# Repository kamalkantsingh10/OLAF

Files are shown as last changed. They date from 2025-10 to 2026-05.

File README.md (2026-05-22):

# 🤖 OLAF

**An open-source AI companion robot. Built in public.**

<p align="center">
  <a href="https://youtube.com/shorts/9D4Txb85EnM">
    OLAF cycling through its expressions — click to watch<br>
    <b>▶ Watch OLAF cycle through its expressions</b>
  </a>
</p>

---

## The Journey: 20 Weeks and Counting

<table>
  <tr>
    <td width="33%" align="center">
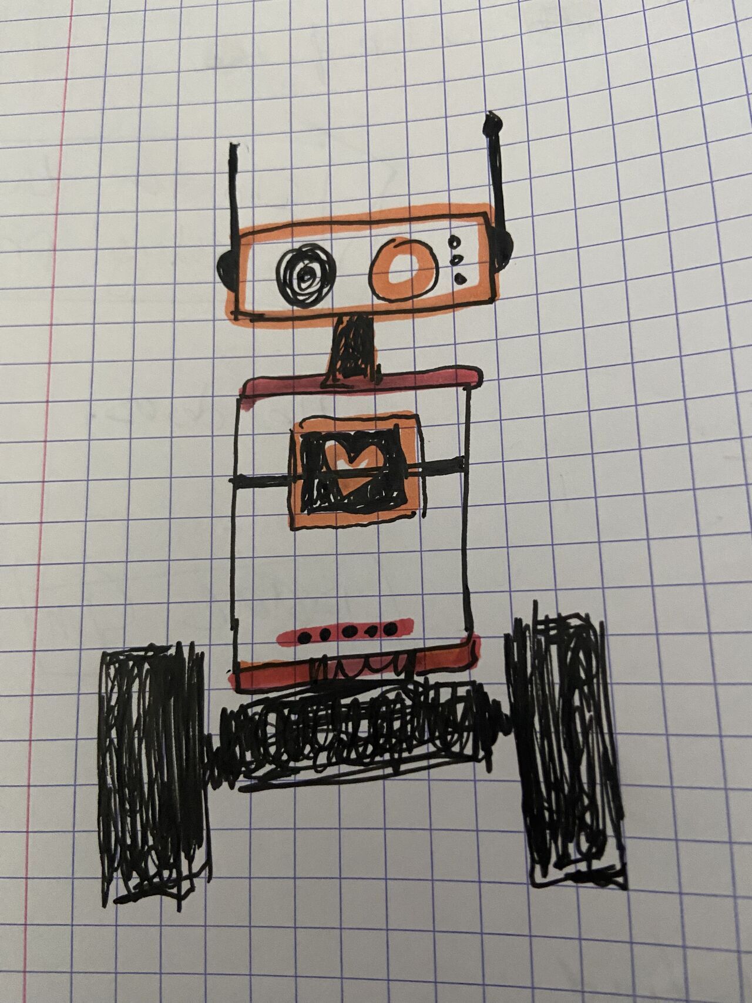
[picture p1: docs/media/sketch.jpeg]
Week 0: Initial Sketch
      <br>
      <b>Week 0</b><br>Initial concept sketch
    </td>
    <td width="33%" align="center">
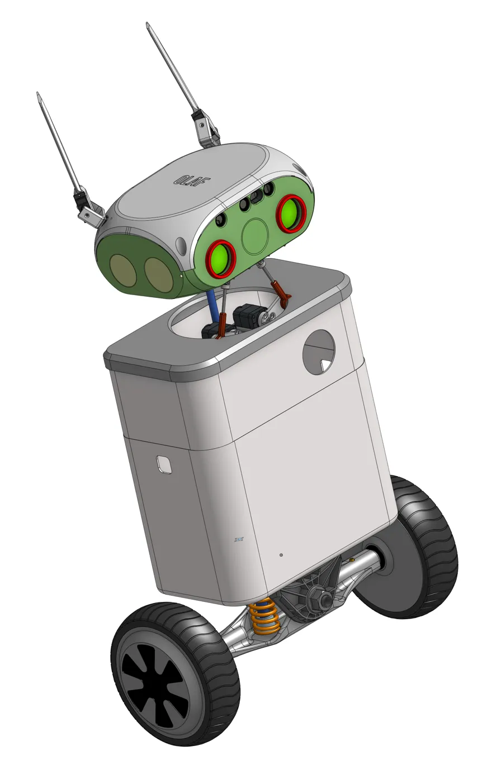
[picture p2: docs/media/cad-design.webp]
Week 8: CAD Design
      <br>
      <b>Week 8</b><br>3D CAD design complete
    </td>
    <td width="33%" align="center">
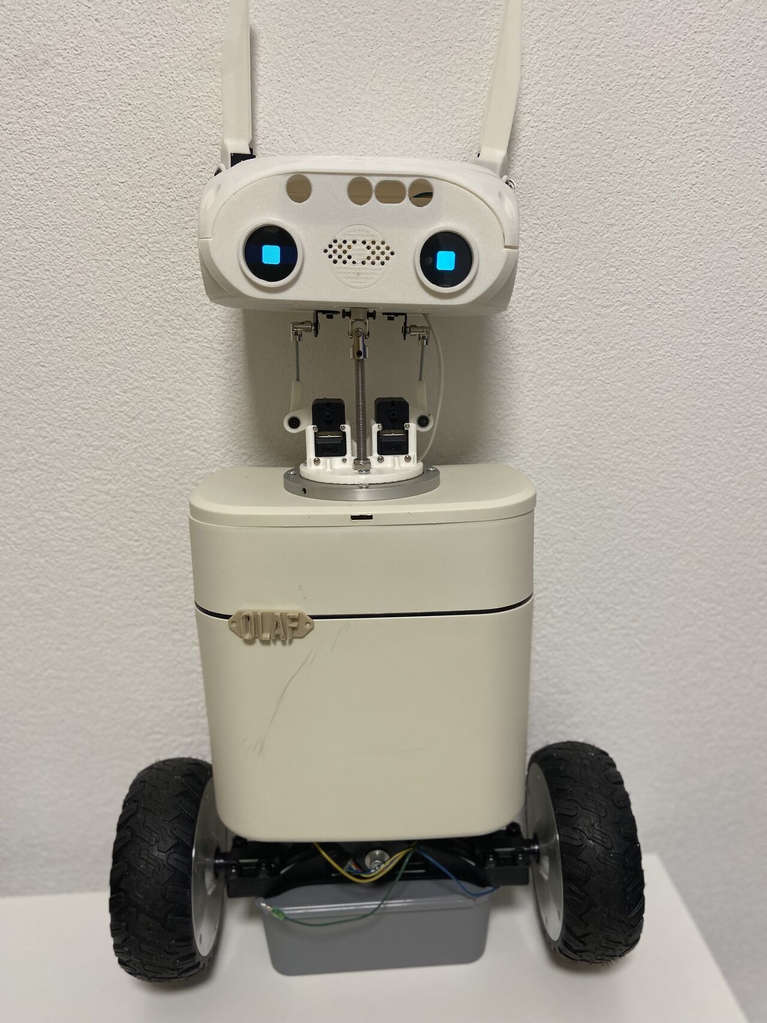
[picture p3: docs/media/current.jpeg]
Week 20: First Module Working
      <br>
      <b>Week 20</b><br>Head alive — eyes, ears & neck expressing
    </td>
  </tr>
</table>

**An active build-in-public project.** Built while relocating cities and starting a new job — learning CAD, ROS2, embedded systems, and AI integration as I go, with AI coding assistants accelerating development. The journey continues!

---

## What is OLAF?

OLAF is a **personality-first robotics framework** that brings AI agents into physical form. Think R2D2's charm meeting modern AI capabilities — a 2-3 foot tall companion that communicates through expressive OLED eyes, articulated ears (Chappie-inspired), an animated heart display, R2D2-style beeps, and LED status indicators.

**This is not another voice assistant in a box.**

When you BUILD your AI companion, something fundamental changes. It becomes a partner, not a servant. JARVIS challenges Tony Stark's ideas. R2D2 takes initiative. The difference? Tony BUILT JARVIS. Luke CHOSE R2D2 and they grew together. **Building creates relationship, and relationship enables true collaboration.**

---

## The Problem We're Solving

AI assistants (Alexa, Siri, ChatGPT, Claude) have impressive reasoning but remain fundamentally **disembodied** — trapped in screens and speakers. Meanwhile, building physical AI with personality forces impossible choices:

| Option | What You Get | What You Lose |
|---|---|---|
| **Commercial robots** (Boston Dynamics, Vector) | Polish, capability | $1000s+, closed-source, no customization |
| **Educational platforms** (Poppy, Niryo) | Modularity, learning | AI integration, personality, high cost |
| **ROS2 robots** (Linorobot2, Andino) | Excellent navigation | Zero personality, assistant features |
| **Hobbyist kits** (Otto DIY) | Affordable, charming | Limited capabilities, no AI |
| **Closed AI robots** (HIWONDER) | AI + robotics bridge | Generic design, closed ecosystem |

**The Core Gap:** No open-source framework integrates modular architecture + AI conversation + personality expression + practical assistance + maker-accessible approach + community ecosystem.

**The Opportunity:** All the pieces are finally here — 3D printers, powerful LLMs, modern SBCs (Raspberry Pi 5), AI coding assistants, local AI accelerators (Hailo). **This is the democratization moment.** The future of embodied AI belongs to builders, not just consumers.

---

## Architecture: Three Layers, Five Modules

> **Repo scope (Phase 2, 2026-05-15).** This repository is the **OLAF body / expression engine** — the Orchestration + Module layers below. The Intelligence Layer (STT, reasoning, personality, mood/emotion decisions) is a **separate sibling project, `olaf_companion`**, which publishes 4 canonical ROS 2 topics (`mood`, `activity`, `speech_emotion`, `vocalization`). This repo subscribes to those and renders them on the body. The "personality-first" vision is unchanged at the *system* level; it's just split across two repos. See `docs/sprint-change-proposal-2026-05-15.md`.

```
┌─────────────────────────────────────────────────────────────────┐
│   INTELLIGENCE LAYER (Hybrid AI) — sibling repo olaf_companion  │
│                                                                 │
│  Local AI (Hailo-accelerated):                                 │
│    • Whisper STT (<200ms latency)                              │
│    • Real-time vision processing                               │
│                                                                 │
│  Cloud AI Agents (Claude/GPT-4):                               │
│    • Natural language understanding                            │
│    • Complex reasoning & decision-making                       │
│    • Tool use, function calling, multi-step planning           │
│                                                                 │
└──────────────────────┬──────────────────────────────────────────┘
                       │ 4 canonical ROS 2 topics
                       │ (mood · activity · speech_emotion · vocalization)
┌──────────────────────▼──────────────────────────────────────────┐
│              ORCHESTRATION LAYER  ◀── THIS REPO                 │
│      Raspberry Pi 5 16GB + Fusion HAT+ + Hailo AI Kit          │
│               Ubuntu 24.04 • ROS2 Jazzy                         │
│                                                                 │
│  • Expression Engine (subscribes to olaf_companion's 4 topics) │
│  • Composes activity → mood → speech_emotion → vocalization    │
│  • Renders pose/LED/eye/heart from expression_map.yaml         │
│  • Direct Hardware Control (servos, LEDs, kickstand via HAT)   │
│  • I2C Master for ESP32 modules                                │
│                                                                 │
└──┬───────┬───────┬─────────────────┬───────────────────────────┘
   │       │       │                 │
   │I2C    │USB×2  │HAT WS2812       │HAT PWM
   │       │       │                 │
┌──▼───┐ ┌─▼─────────────┐ ┌────────▼───┐ ┌──▼──────┐
│ HEAD │ │ WAVESHARE USB │ │ INDICATOR  │ │KICKSTAND│
│ESP32 │ │ Neck + Ears   │ │ 24 LEDs    │ │ Servos  │
│(0x10)│ │ Servo Adapters│ │ (3 strips) │ │(at base)│
└──────┘ └───────────────┘ └────────────┘ └──▲──────┘
┌──▼───┐                                      │
│ BASE │                                      │
│ESP32 │                                      │
│(0x11)│                                      │
└──────┘
```

### The Five Modules (MECE Principle)

Each module owns its domain exclusively — no cross-dependencies. **Hybrid control:** ESP32s for real-time tasks, Pi direct control for latency-tolerant hardware.

**1. HEAD Module (ESP32, I2C 0x10)**
- **Hardware:** 2× GC9A01 round OLED eyes (240×240, SPI 30-60 FPS), ESP32-S3 for real-time eye animation
- **Personality:** Animated eye expressions, smooth emotional transitions, blink patterns
- **Why ESP32:** 60 FPS animation requires dedicated real-time control

**2. BASE Module (ESP32, I2C 0x11)**
- **Hardware:** Two-wheel inverted pendulum, hoverboard BLDC motors, ODrive v3.6 (UART), BNO085 9-axis AHRS (200Hz on-chip sensor fusion)
- **Control:** 200Hz PID balancing loop (hard real-time, Linux can't guarantee this)
- **Why ESP32:** Self-balancing requires hard real-time guarantees

**3. NECK Module (Pi-controlled, USB Serial)**
- **Hardware:** 3× Feetech STS3215 servos (pan/tilt/roll), Waveshare Bus Servo Adapter
- **Personality:** Head orientation, expressive gestures (tilts, nods, shakes) with organic easing
- **Why Pi Direct:** USB serial via Waveshare adapter — no soldering, plug-and-play

**4. EARS Module (Pi-controlled, USB Serial)**
- **Hardware:** 4× Feetech SCS0009 servos (2-DOF × 2 ears), Waveshare Bus Servo Adapter
- **Personality:** Chappie-inspired ears — perked = alert, drooping = sad, swiveling = curious
- **Why Pi Direct:** USB serial via Waveshare adapter — no soldering, plug-and-play

**5. INDICATOR Module (Pi-controlled, Fusion HAT WS2812)**
- **Hardware:** 3× 8-LED WS2812 strips (24 LEDs, daisy-chained)
- **Functions:** interaction state (listening/working/speaking) · module health · PID visualization
- **Why Pi Direct:** Single data line via Fusion HAT WS2812 port

**Additional Pi-controlled hardware:** 4" heart display (animated beating heart) · kickstand (2× landing-gear servos via HAT PWM) · I2S speaker via HAT.

### Why This Architecture?

- **Hybrid control topology** — ESP32s for the two real-time-critical jobs (60 FPS eyes, 200Hz balancing); Pi direct (via Fusion HAT) for everything else. Minimal soldering, fewer firmware projects, maximum reliability.
- **Modular MECE** — each module completable in 1-2 weekend sprints, independently testable, contribution-friendly.
- **Hybrid intelligence** — local AI (Hailo) for fast/private sensing; cloud agents for sophisticated reasoning.
- **ROS2 foundation** — industry-standard pub/sub on ROS2 Jazzy / Ubuntu 24.04, with a rich ecosystem (SLAM, navigation, sensor fusion).

---

## How Expression Works

The expression engine is a ROS2 node that turns "what the companion is feeling/doing" into coordinated motion + light across every channel — in real time, from a single data-driven map.

```
companion topics ─▶ activity base ─▶ + mood bias ─▶ + speech_emotion ─▶ + vocalization
(mood/activity/      (posture)        (LED tint /     (12 authored        (transient
 speech/voc)                           idle drift)     emotions)            gestures)
                                                              │
                                                              ▼
                                          eyes (OLED) · ears · neck · WS2812 LEDs
```

- **Single source of truth:** `ros2/src/expression_engine/config/expression_map.yaml` (+ `neck_motion.yaml`, `ears_motion.yaml`). See the [config index](ros2/src/expression_engine/config/README.md).
- **Additive composition:** later layers ride on top of earlier ones, so a vocalization gesture never wipes the underlying emotional pose.
- **Hand-authored, hardware-tuned:** every emotion is authored, then frozen after a pass on the real avatar.

---

## Current Status

**🔄 Active build-in-public (Phase 2 — Expression Engine).** This is a work-in-progress; here's what's real today.

**✅ Working on real hardware:**
- **Head / eyes** — 2× OLED eyes animated by ESP32 firmware; a full set of distinct expressions (the video above)
- **Ears** — 4× SCS0009 servos: perk / droop / swivel, hardware-calibrated
- **Neck** — 3× STS3215 servos: pan / tilt / roll with organic easing
- **Expression engine (ROS2 Jazzy)** — subscribes to the companion's 4 canonical topics and drives eyes + ears + neck + LEDs in sync
- **Idle behaviour** — head drifts to sleep when idle, stirs awake on activity
- **Status LEDs** — WS2812 strips reflect listening / working / speaking

**🔨 In progress / next:**
- Expression authoring finalization (Epic 7 — in review: speech emotions, vocalizations, activity postures, mood→LED tint)
- Heart display animation (Epic 8)
- Self-balancing base — PID tuning (experimental)
- SLAM navigation (deferred)

**🔗 Companion brain:** the AI/intelligence layer lives in the sibling repo **`olaf_companion`**, which publishes the 4 topics this body renders.

**Realistic timeline:** a complex build done in spare time while working full-time. Progress is incremental, iterative, and documented as it happens.

---

## 📹 Demo Videos

### May 2026
- **OLAF expression cycling** — *2026-05-20* — the expression engine cycling through OLAF's authored emotions on real hardware (OLED eyes, articulated ears, 3-DOF neck). [▶ Watch on YouTube](https://youtube.com/shorts/9D4Txb85EnM)

---

## Repository Organization

**Module-first structure.** Everything for a module lives in one place.

```
modules/
├── head/             # OLED eyes (ESP32, I2C 0x10)
├── base/             # Self-balancing (ESP32, I2C 0x11)
├── neck/             # 3-DOF servos (Pi USB serial)
├── ears/             # Articulated ears (Pi USB serial)
├── indicator/        # WS2812 LED strips (Pi Fusion HAT)
└── shared/           # Shared ESP32 libraries
```

**ESP32 modules** (head, base): `firmware/` (PlatformIO) · `hardware/` (3D models + BOM) · `tests/` · `wiring.md`.
**Pi-controlled modules** (neck, ears, indicator): `hardware/` · `tests/` · `assembly.md`.

**ROS2 lives separately:**
```
ros2/src/
├── olaf_drivers/       # Driver logic (head_ears, neck, base, torso)
├── expression_engine/  # Phase 2: renders olaf_companion's 4 canonical topics
└── olaf_ai/            # (deferred) STT/agents now in olaf_companion
```

**Full details:** see [repository-structure.md](docs/architecture/repository-structure.md).

---

## License & Credits

**License:** Open Source (TBD: MIT or Apache 2.0)

**Builder:** [Kamal Singh](https://www.linkedin.com/in/kamal-singh)
- 15 years in tech (5 at Amazon) · 1 year intentional AI deep-dive · MBA + full-stack (hardware + software + AI)

**Inspiration:** R2D2 (non-verbal personality) · JARVIS (AI partner, not servant) · Chappie (expressive ears) · Wall-E (friendly retro-futurism).

**Built with:** AI coding assistants (Claude, GPT-4) · Raspberry Pi 5 16GB / Ubuntu 24.04 · Sunfounder Fusion HAT+ · Hailo AI Kit (26 TOPS) · ROS2 Jazzy · ESP32-S3 · Waveshare Bus Servo Adapters · OnShape · PlatformIO.

---

## Tags

`#BuildInPublic` `#Robotics` `#ROS2` `#PhysicalAI` `#OpenSource` `#MakerMovement` `#AI` `#LearnInPublic` `#EmbodiedAI` `#ModularRobotics`

---

<p align="center">
  <i>"Feel alive first, be useful second."</i>
</p>

<p align="center">
  <b>Star ⭐ this repo if you believe the future of AI should be open and collaborative!</b>
</p>

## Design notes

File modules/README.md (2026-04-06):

# OLAF Modules

Complete subsystems for OLAF's four smart peripheral modules.

## Module Overview

Each module is a **self-contained unit** with its own:
- **Firmware** (ESP32 code)
- **Hardware** (PCB designs, 3D models)
- **Tests** (Module-specific integration tests)
- **Diagnostics** (Debug and calibration tools)
- **Scripts** (Build, flash, test automation)
- **Documentation** (Wiring, assembly guides)

## Modules

| Module | I2C Address | Key Components | Status |
|---|---|---|---|
| **[head-ears](head-ears/)** | 0x08 | 2× OLED eyes, 2× articulated ears, floor projector control | In Development |
| **[neck](neck/)** | 0x09 | 3-DOF servo array, 2× presence sensors | Designed |
| **[torso](torso/)** | 0x0A | Heart display, thermal printer, battery, Pi housing | In Development |
| **[base](base/)** | 0x0B | ODrive motors, BNO085 AHRS IMU, self-balancing | Designed |

## Quick Start

### Build a Module

```bash
cd modules/head-ears/firmware
pio run
```

### Flash a Module

```bash
cd modules/head-ears/firmware
pio run --target upload
```

### Test a Module

```bash
cd modules/head-ears
pytest tests/
```

### Run Diagnostics

```bash
cd modules/head-ears
python3 diagnostics/projector_diagnostic.py
```

## Development Workflow

1. **Navigate to module:** `cd modules/head-ears`
2. **Everything is here:**
   - Firmware code: `firmware/src/`
   - Hardware designs: `hardware/pcb/`, `hardware/mechanical/`
   - Tests: `tests/`
   - Tools: `diagnostics/`, `scripts/`
   - Docs: `wiring.md`, `assembly.md`, `README.md`

3. **Build → Flash → Test:**
   ```bash
   cd firmware && pio run --target upload
   cd ../tests && pytest
   cd ../diagnostics && python3 module_health.py
   ```

## Shared Resources

**Location:** `modules/shared/`

- **Firmware:** I2C protocol, OTA handlers, utilities
- **Hardware:** KiCad libraries, common 3D parts

All modules include shared libraries:
```ini
# In platformio.ini
lib_extra_dirs = ../../shared/firmware
```

## Module Architecture

Each module follows the **Smart Peripheral Pattern**:

1. **I2C Slave Interface:** Receives commands from Raspberry Pi
2. **Hardware Drivers:** Direct control of sensors/actuators
3. **Animation Engine:** Local execution of motion/display patterns
4. **Real-Time Control:** Critical timing loops (e.g., 200Hz PID on base)

**Example:** Head+Ears receives `PROJECTOR_ON` via I2C, then autonomously controls power (optocoupler) and focus (servo) without further Pi intervention.

## System Integration

Modules communicate via:
- **I2C bus:** Commands from Pi, sensor data to Pi
- **ROS2 topics:** High-level semantic interface (via driver nodes in `ros2/src/olaf_drivers/`)
- **Shared ground:** All modules share common electrical ground

See `hardware/wiring/` for inter-module wiring diagrams.

## Adding a New Module

1. Create directory: `modules/new-module/`
2. Copy structure from existing module (e.g., `head-ears/`)
3. Update I2C address in `firmware/platformio.ini`
4. Create ROS2 driver in `ros2/src/olaf_drivers/new_module_driver/`
5. Document in `new-module/README.md`

## Resources

- **System Architecture:** See `docs/architecture.md`
- **I2C Protocol:** See `modules/shared/firmware/i2c-protocol/`
- **Wiring Guide:** See `docs/guides/wiring-guide.md` and `hardware/wiring/`
- **Module Documentation:** See each module's `README.md`

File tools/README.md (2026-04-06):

# Tools

Development and debugging utilities for OLAF.

## Structure

```
tools/
├── diagnostics/    # System diagnostics
├── calibration/    # Sensor/servo calibration
├── simulators/     # Hardware-in-the-loop simulators
└── utils/          # General utilities
```

## Diagnostics

**Location:** `tools/diagnostics/`

System health checks and debugging:

### i2c_scanner.py

Scan I2C bus for connected modules:

```bash
python3 tools/diagnostics/i2c_scanner.py
```

Output:
```
Found devices at: 0x08 (Head+Ears), 0x09 (Neck), 0x0A (Torso), 0x0B (Base)
```

### module_health_check.py

Check health status of all modules:

```bash
python3 tools/diagnostics/module_health_check.py
```

Reports:
- Firmware version
- Uptime
- Error counts
- Temperature
- I2C communication status

### odrive_diagnostic.py

ODrive motor controller diagnostics:

```bash
python3 tools/diagnostics/odrive_diagnostic.py
```

Checks:
- Motor calibration status
- Encoder alignment
- Current limits
- Bus voltage

## Calibration

**Location:** `tools/calibration/`

Calibrate sensors and actuators:

### servo_calibrator.py

Calibrate servo ranges and positions:

```bash
# Interactive calibration
python3 tools/calibration/servo_calibrator.py --module head-ears

# Auto-calibrate with defaults
python3 tools/calibration/servo_calibrator.py --module neck --auto
```

Saves calibration to `config/firmware/{module}_servo_cal.json`

### imu_calibrator.py

Calibrate BNO085 IMU (9-axis AHRS with on-chip sensor fusion):

```bash
python3 tools/calibration/imu_calibrator.py
```

BNO085 calibration procedure:
1. Place robot stationary on flat surface for ~30 seconds (accel/gyro auto-calibrate)
2. Slowly rotate robot in figure-8 pattern for magnetometer calibration
3. Script saves calibration data to ESP32 flash via `sh2_saveDcdNow()`
4. Tare sets current upright orientation as pitch=0° reference

### camera_calibrator.py

Calibrate RGBD camera intrinsics:

```bash
python3 tools/calibration/camera_calibrator.py --checkerboard 9x6 --size 0.025
```

Uses checkerboard pattern for calibration.

## Simulators

**Location:** `tools/simulators/`

Test without physical hardware:

### i2c_module_simulator.py

Simulate ESP32 modules for development:

```bash
# Simulate all modules
python3 tools/simulators/i2c_module_simulator.py

# Simulate specific module
python3 tools/simulators/i2c_module_simulator.py --module head-ears
```

Emulates I2C slave behavior, useful for:
- ROS2 driver development without hardware
- Integration testing
- CI/CD pipelines

## Utilities

**Location:** `tools/utils/`

General-purpose utilities:

### log_analyzer.py

Analyze ROS2 and firmware logs:

```bash
python3 tools/utils/log_analyzer.py logs/olaf_2024-01-15.log
```

Extracts:
- Error patterns
- Performance metrics
- Event timelines

## Usage Examples

### Initial Setup

```bash
# 1. Scan for modules
python3 tools/diagnostics/i2c_scanner.py

# 2. Check module health
python3 tools/diagnostics/module_health_check.py

# 3. Calibrate servos
python3 tools/calibration/servo_calibrator.py --module head-ears
python3 tools/calibration/servo_calibrator.py --module neck

# 4. Calibrate IMU (for base module)
python3 tools/calibration/imu_calibrator.py
```

### Development Without Hardware

```bash
# Start I2C simulator
python3 tools/simulators/i2c_module_simulator.py &

# Launch ROS2 drivers (will connect to simulator)
ros2 launch olaf_bringup drivers.launch.py
```

### Troubleshooting

```bash
# Module not responding?
python3 tools/diagnostics/i2c_scanner.py
python3 tools/diagnostics/module_health_check.py

# Motors behaving oddly?
python3 tools/diagnostics/odrive_diagnostic.py

# Check logs
python3 tools/utils/log_analyzer.py logs/latest.log
```

## Requirements

Install Python dependencies:

```bash
pip install smbus2 pyserial numpy opencv-python
```

Or via Poetry (from project root):

```bash
poetry install
```

## Adding New Tools

When creating new tools:

1. Place in appropriate category folder
2. Make executable: `chmod +x tool.py`
3. Add shebang: `#!/usr/bin/env python3`
4. Include `--help` argument
5. Document usage in this README

Example template:

```python
#!/usr/bin/env python3
"""
Brief description of tool.
"""
import argparse

def main():
    parser = argparse.ArgumentParser(description="Tool description")
    parser.add_argument("--option", help="Option description")
    args = parser.parse_args()

    # Tool logic here

if __name__ == "__main__":
    main()
```

## Resources

- [I2C Protocol Specification](../docs/api/i2c-protocol.md)
- [Calibration Guide](../docs/guides/calibration.md)

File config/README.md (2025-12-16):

# Configuration

Runtime configuration files for OLAF's firmware, ROS2 nodes, and I2C bus.

## Structure

```
config/
├── i2c/        # I2C bus configuration
├── ros2/       # ROS2 node parameters
└── firmware/   # Firmware configuration (WiFi, OTA URLs)
```

## I2C Configuration

**Location:** `config/i2c/`

### bus_config.yaml

I2C bus settings:

```yaml
bus_speed: 400000  # 400 kHz (standard) or 1000000 (fast mode)
bus_number: 1      # /dev/i2c-1 (Raspberry Pi default)
timeout_ms: 100    # Read/write timeout

modules:
  head_ears:
    address: 0x08
    enabled: true
  neck:
    address: 0x09
    enabled: true
  torso:
    address: 0x0A
    enabled: true
  base:
    address: 0x0B
    enabled: true
```

## ROS2 Configuration

**Location:** `config/ros2/`

### drivers.yaml

Hardware driver node parameters:

```yaml
head_ears_driver:
  ros__parameters:
    i2c_address: 0x08
    update_rate: 30.0  # Hz
    projector:
      default_focus: 128
      power_timeout: 5.0  # seconds
    eyes:
      brightness: 200
      fps: 60

neck_driver:
  ros__parameters:
    i2c_address: 0x09
    servo_count: 3
    movement_smoothing: 0.8

# ... more driver configs
```

Load with:
```bash
ros2 launch olaf_bringup drivers.launch.py config:=config/ros2/drivers.yaml
```

### personality.yaml

Personality engine parameters:

```yaml
emotion_engine:
  ros__parameters:
    default_emotion: neutral
    transition_time: 1.0  # seconds
    energy_level: 0.7

expression_sync:
  ros__parameters:
    max_latency_ms: 500
    sync_eyes_ears: true
```

### navigation.yaml

Nav2 stack parameters (extensive, see Nav2 docs):

```yaml
controller_server:
  ros__parameters:
    use_sim_time: false
    controller_frequency: 20.0
    # ... more Nav2 params
```

## Firmware Configuration

**Location:** `config/firmware/`

### wifi_config.json

WiFi credentials for OTA updates (gitignored, template provided):

```json
{
  "ssid": "YourNetworkName",
  "password": "YourPassword",
  "hostname": "olaf-robot"
}
```

**Security Note:** Never commit this file! Use `wifi_config.json.template` as reference.

### ota_config.yaml

OTA update server configuration:

```yaml
ota_server:
  host: "192.168.1.100"  # Raspberry Pi IP
  port: 8080
  check_interval: 3600  # seconds (1 hour)
  auto_update: false

modules:
  head_ears:
    firmware_url: "http://192.168.1.100:8080/firmware/head-ears/latest.bin"
    version_url: "http://192.168.1.100:8080/firmware/head-ears/version.txt"
  # ... more modules
```

### module_calibration/

Per-module calibration data:

- `head_ears_servo_cal.json` - Ear servo calibration
- `neck_servo_cal.json` - Neck servo calibration
- `base_imu_cal.json` - IMU calibration offsets
- `camera_intrinsics.yaml` - Camera calibration

Generated by calibration tools (`tools/calibration/`).

## Environment-Specific Configs

Use different configs for dev/production:

```bash
# Development (with simulator)
ros2 launch olaf_bringup olaf.launch.py config:=config/ros2/drivers_sim.yaml

# Production (on robot)
ros2 launch olaf_bringup olaf.launch.py config:=config/ros2/drivers.yaml
```

## Configuration Priority

1. **Command-line arguments** (highest priority)
2. **Environment variables**
3. **Config files** (this directory)
4. **Default values** (in source code)

Example:
```bash
# Override config file setting
ros2 run olaf_drivers head_ears_driver --ros-args -p i2c_address:=0x10
```

## Version Control

- **Commit:** Config templates (`.template` suffix), default configs
- **Gitignore:** Secrets (WiFi passwords), machine-specific settings
- **Document:** All parameters in config files with comments

## Editing Configs

### YAML Files

Use YAML-aware editor (VS Code with YAML extension):

```bash
code config/ros2/drivers.yaml
```

Validate YAML syntax:
```bash
yamllint config/ros2/drivers.yaml
```

### JSON Files

Pretty-print JSON:
```bash
python3 -m json.tool config/firmware/wifi_config.json
```

## Best Practices

1. **Document all parameters** - Add inline comments explaining purpose
2. **Use meaningful defaults** - Configs should work out-of-the-box
3. **Validate on load** - Check for missing/invalid values at runtime
4. **Version configs** - Tag configs with compatible firmware/ROS2 versions
5. **Keep secrets separate** - Use `.env` files or secrets managers

## Troubleshooting

### Module Not Responding

Check I2C address in config matches firmware:
```bash
cat config/i2c/bus_config.yaml | grep address
i2cdetect -y 1
```

### ROS2 Node Fails to Start

Validate YAML syntax:
```bash
yamllint config/ros2/drivers.yaml
```

Check parameter names:
```bash
ros2 param list /head_ears_driver
```

### OTA Update Fails

Verify OTA server is reachable:
```bash
curl http://192.168.1.100:8080/firmware/head-ears/version.txt
```

## Resources

- [ROS2 Parameter Guide](https://docs.ros.org/en/humble/Concepts/About-ROS-2-Parameters.html)
- [YAML Specification](https://yaml.org/spec/1.2.2/)
- [I2C Protocol Documentation](../docs/api/i2c-protocol.md)

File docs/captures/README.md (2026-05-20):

# Captures

Webcam shots of OLAF for Epic 7 expression verification (dev-PC cam → bot).
Capture method: see memory `reference_webcam_capture.md` (native MJPEG via
gst pipewiresrc; do NOT decode→re-encode — green-band artifact).

- **Stills** (`YYYYMMDD-HHMMSS-<emotion>.jpg`): tracked — authoring evidence.
- **Video** (`*.avi` etc.): git-ignored — kept locally; analysed by
  extracting frames (`ffmpeg -i clip.avi -vf "select=eq(n\,N)" -frames:v 1`)
  at t=0 / mid-ease / settled to verify easing & gesture transitions.
- `bot_*.jpg` raw multi-frame grabs are scratch (ignored); keep only the
  meaningfully-named final shot.

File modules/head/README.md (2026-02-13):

# Head Module

**Controller:** ESP32-S3 (I2C address 0x08)

## Overview

The Head module controls OLAF's expressive OLED eyes. It runs on a dedicated ESP32 to achieve 30-60 FPS eye animations with real-time responsiveness.

## Hardware

- ESP32-S3-DevKitC-1 (N16R8)
- 2x GC9A01 round OLED displays (240x240, SPI)
- 1x WS2812 8-LED strip (face status indicator)

## Interfaces

| Interface | Purpose |
|---|---|
| I2C (slave) | Commands from Pi (expressions, blink, look direction, LED state) |
| SPI x2 | OLED eye displays |
| GPIO4 | WS2812 LED strip data |

## ROS2 Topics

| Topic | Type | Description |
|---|---|---|
| `/head/expression` | String | Set eye expression (happy, sad, curious, etc.) |
| `/head/blink` | Bool | Trigger blink animation |
| `/head/look` | Point | Look direction (x, y coordinates) |

## OTA Firmware Updates

The head module supports over-the-air firmware updates via ArduinoOTA (WiFi).

**Prerequisites:**
- ESP32 connected to same WiFi network as development machine
- mDNS hostname: `olaf-head.local`
- OTA password: configured in `firmware/src/main.cpp`

**Flash via PlatformIO:**
```bash
cd modules/head/firmware
pio run -t upload
```

PlatformIO is configured with `upload_protocol = espota` and `upload_port = olaf-head.local`, so `pio run -t upload` automatically uses OTA.

**Partition scheme:** `default_16MB.csv` — dual 6.5MB app partitions with automatic rollback support. If a new firmware fails to boot, the ESP32 reverts to the previous working partition.

**First-time flash:** OTA requires working firmware already on the ESP32. For initial flash or recovery, use USB:
```bash
pio run -t upload --upload-port /dev/ttyUSB0
```

## Power

- 5V from 36V→5V buck converter
- ESP32 provides 3.3V to OLEDs

## Directory Structure

```
head/
├── firmware/           # ESP32 firmware (PlatformIO)
│   ├── src/
│   ├── include/
│   ├── test/
│   └── platformio.ini
├── hardware/
│   ├── mechanical/     # 3D models
│   └── bom.csv
├── tests/              # Integration tests
├── diagnostics/        # Eye test patterns
├── scripts/            # Build, flash, calibrate
├── wiring.md           # Pin assignments
├── assembly.md         # Assembly guide
└── README.md
```

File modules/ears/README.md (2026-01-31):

# Ears Module

**Controller:** Raspberry Pi (via USB serial to Waveshare Bus Servo Adapter)

## Overview

The Ears module controls OLAF's articulated ears for emotional expression. Two 2-DOF ears (4 servos total) are controlled directly by the Pi via a Waveshare Bus Servo Adapter connected over USB.

## Hardware

- 4x Feetech SCS0009 serial bus servos
- 1x Waveshare Bus Servo Adapter (A) in USB mode
- 2x ear mechanisms (2-DOF each: rotate + tilt)

## Interfaces

| Interface | Purpose |
|---|---|
| USB Serial | Pi to Waveshare adapter |
| Serial bus | Adapter to SCS0009 servos (daisy-chained) |

## ROS2 Topics

| Topic | Type | Description |
|---|---|---|
| `/ears/emotion` | String | Set ear pose for emotion (alert, relaxed, sad, etc.) |
| `/ears/perk` | Bool | Quick perk-up animation |
| `/ears/left_pose` | Float32[2] | Left ear angles [rotate, tilt] |
| `/ears/right_pose` | Float32[2] | Right ear angles [rotate, tilt] |

## Power

- 12V from 36V→12V buck converter (to Waveshare adapter)
- Waveshare adapter provides servo power

## Directory Structure

```
ears/
├── hardware/
│   ├── mechanical/     # 3D models for ear mechanisms
│   └── bom.csv
├── tests/              # Integration tests
├── diagnostics/        # Servo test scripts
├── scripts/            # Calibration scripts
├── assembly.md         # Assembly guide
└── README.md
```

## Notes

- No firmware required - controlled by ROS2 node `olaf_ears`
- Servos are daisy-chained on serial bus
- USB connection provides reliable communication without custom wiring

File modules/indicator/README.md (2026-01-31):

# Indicator Module

**Controller:** Raspberry Pi (via Fusion HAT+ WS2812 port)

## Overview

The Indicator module provides visual feedback through 24 addressable RGB LEDs arranged in 3 strips of 8 LEDs each. Controlled directly by the Pi through the Fusion HAT's WS2812 port.

## Hardware

- 3x WS2812 8-LED strips (24 LEDs total, daisy-chained)
- Connected to Fusion HAT+ WS2812 port (ZH1.5 connector)

## LED Strip Assignments

| Strip | LEDs | Purpose |
|---|---|---|
| Strip 1 | 0-7 | **Interaction** — listening (blue pulse), thinking (yellow spin), speaking (green wave) |
| Strip 2 | 8-15 | **Module Status** — health indicators for Head, Base, Neck, Ears, AI |
| Strip 3 | 16-23 | **PID Visualization** — self-balancing state (tilt direction, correction intensity) |

## ROS2 Topics

| Topic | Type | Description |
|---|---|---|
| `/indicator/interaction` | String | Set interaction state (listening, thinking, speaking, idle) |
| `/indicator/status` | UInt8[5] | Module health status array [head, base, neck, ears, ai] |
| `/indicator/pid` | Float32[3] | PID visualization [pitch, correction, intensity] |
| `/indicator/raw` | UInt8[72] | Direct LED control (24 LEDs × RGB) |

## Power

- 5V from 2000mAh battery via Fusion HAT

## Directory Structure

```
indicator/
├── hardware/
│   ├── mechanical/     # 3D models for LED strip mounts
│   └── bom.csv
├── tests/              # Integration tests
├── diagnostics/        # LED test patterns
└── README.md
```

## Notes

- No firmware required - controlled by ROS2 node `olaf_indicator`
- Single data line connection via Fusion HAT
- All 3 strips daisy-chained (data out → data in)

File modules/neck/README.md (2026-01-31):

# Neck Module

I2C Address: **0x09**

## Overview

The Neck module serves as OLAF's voice interaction status indicator and houses the neck articulation servos. Key features:

- **Voice Indicator**: 8× WS2812B LED strip displays real-time voice interaction states
- **Neck Servos**: 3× Feetech STS3215 servos (pan, tilt, roll)
- **Kickstand**: 1× Feetech STS3215 servo for stability deployment
- **mmWave Sensors**: 2× HLK-LD2461 24GHz radar for 360° presence detection
- **ESP32-S3**: 240MHz dual-core MCU with 16MB flash, 8MB PSRAM
- **OTA Updates**: Over-the-air firmware updates via WiFi

## Hardware

See `hardware/` directory for PCB designs and 3D models.

## Firmware

See `firmware/` directory for ESP32 code.

### Voice Indicator Animations

The Neck module features a `VoiceIndicator` class that controls the 8× WS2812B LED strip with 7 distinct animation states for voice interaction feedback. All animations are **perfectly symmetrical** across the center for visual balance.

#### Animation States

| State | Trigger | Visual Effect | Technical Details |
|---|---|---|---|
| **WAKE_UP** | Wake word detected | Fast power-up burst from center outward with color shift (Blue → Cyan → White), ending in bright flash | 70ms steps, expands symmetrically from center |
| **LISTENING** | Actively listening | Fast blue pulse waves radiating from center with subtle sparkles for organic feel | 30ms updates, 1s wave cycle, dual-wave overlaps |
| **RESPONDING** | Speaking answer | Dynamic symmetrical VU meter with fast-rotating rainbow gradient and frequent brightness peaks | 40ms updates, rainbow rotation, 2-3 simultaneous peaks |
| **WORKING** | Processing task | Rapid bouncing chase from edges to center and back with cyan→purple gradient and comet tail | 35ms updates, smooth bounce motion, bright leading edge |
| **RECEIVING_TRANSMISSION** | Receiving data | Fast symmetrical data stream with mixed colors (white/cyan/blue) and quick fade trails | 50ms updates, 2-3 packet pairs, 60% fade rate |
| **GOING_TO_SLEEP** | Preparing to sleep | Sunset fade transitioning through color temperatures (warm amber → deep red → off) | 1.8s total duration, smooth color/brightness fade |
| **SLEEPING** | Idle state | Gentle breathing pulse in dark blue with subtle center-outward brightness variation | 3.5s breath cycle, very dim (5-15 brightness) |

#### Usage Example

```cpp
#include "voice_indicator.h"

CRGB leds[8];
VoiceIndicator voiceIndicator(leds, 8);

void setup() {
  FastLED.addLeds<WS2812B, LED_DATA_PIN, GRB>(leds, 8);
  FastLED.setBrightness(5);
  voiceIndicator.begin();
}

void loop() {
  voiceIndicator.update();  // Non-blocking, call every loop

  // Change state based on voice interaction
  // voiceIndicator.setState(VoiceIndicator::LISTENING);
}
```

#### Animation Design Philosophy

- **Symmetry**: All patterns mirror perfectly across the center LED axis
- **Dynamic Motion**: Fast update rates (30-70ms) create fluid, organic movement
- **Energy Variation**: Brightness peaks, color shifts, and random elements prevent static feel
- **State Clarity**: Each animation has distinct visual signature for instant recognition
- **Performance**: Non-blocking updates, optimized for ESP32-S3 at 240MHz

#### Files

- `firmware/src/voice_indicator.h` - Class interface and state definitions
- `firmware/src/voice_indicator.cpp` - Animation implementations
- `firmware/src/main.cpp` - Integration example with test cycle

## Wiring

See `wiring.md` for pin assignments and connections.

## Assembly

See `assembly.md` for build instructions.

## Testing

See `tests/` directory for module-specific tests.

## Diagnostics

See `diagnostics/` directory for diagnostic tools.

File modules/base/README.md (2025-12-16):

# Base Module

I2C Address: **0x0B**

## Overview

[To be documented]

## Hardware

See `hardware/` directory for PCB designs and 3D models.

## Firmware

See `firmware/` directory for ESP32 code.

## Wiring

See `wiring.md` for pin assignments and connections.

## Assembly

See `assembly.md` for build instructions.

## Testing

See `tests/` directory for module-specific tests.

## Diagnostics

See `diagnostics/` directory for diagnostic tools.

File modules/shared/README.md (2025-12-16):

# Shared Module Resources

Code and hardware components shared across all modules.

## Firmware

See `firmware/` for shared firmware libraries (I2C protocol, OTA, utilities).

## Hardware

See `hardware/` for shared KiCad libraries and common 3D parts.

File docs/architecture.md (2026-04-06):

# High Level Architecture

## Technical Summary

OLAF is a **hybrid-control robotics system** with AI intelligence, built on a three-layer architecture. The **Orchestration Layer** (Raspberry Pi 5 16GB + Sunfounder Fusion HAT+ + Hailo AI Kit running ROS2 Jazzy on Ubuntu 24.04) provides both central coordination and direct hardware control, while two **Module Layer** ESP32 controllers handle real-time tasks (Head for eye animations, Base for self-balancing). The **Intelligence Layer** combines local AI acceleration (Hailo-accelerated Whisper STT for <200ms speech recognition) with cloud-based AI agents (Claude/GPT-4 APIs for reasoning and personality generation).

Key architectural decisions include: (1) **Hybrid control topology** — Pi directly controls servos via USB (Waveshare Bus Servo Adapters for neck/ears), LEDs via Fusion HAT (WS2812 indicators), and kickstand via HAT PWM, while ESP32s handle real-time tasks requiring dedicated timing, (2) **Reduced ESP32 count** (4→2) eliminates soldering complexity by leveraging Fusion HAT's pre-built interfaces, (3) **I2C for ESP32 communication** (Head 0x10, Base 0x11) achieves 5-20ms latency for eye expressions and motor commands, (4) **Five ROS2 modules** via MECE principle: Head (OLED eyes via ESP32), Base (self-balancing via ESP32), Neck (3-DOF servos via USB), Ears (2-DOF articulated ears via USB), Indicator (24 WS2812 LEDs for interaction/status/PID visualization), (5) **4" Pi display as heart** replaces dedicated Torso ESP32, (6) **Dual battery architecture** — 36V hoverboard battery (motors, servos, ESP32s) with buck converters (36V→12V, 36V→5V), plus 2000mAh 7.4V battery (Pi, HAT, AI HAT, display, WS2812, kickstand) for isolated logic power, (7) **Self-balancing** with 200Hz PID on Base ESP32 using BNO085 IMU (on-chip AHRS) and ODrive, (8) **Kickstand** via model plane landing gear servos (4.8-7.4V) controlled by Pi HAT PWM with long signal wires to base, and (9) OTA firmware updates for the 2 ESP32s enable rapid iteration. This architecture achieves <3s AI response latency, supports 2-4 hour battery runtime, and minimizes soldering through use of pre-built adapter boards.

## Platform and Infrastructure Choice

**Platform: Self-Hosted Embedded Robotics System**

**Core Infrastructure:**
- **Compute Platform**: Raspberry Pi 5 16GB (quad-core ARM Cortex-A76 @ 2.4GHz)
- **Operating System**: Ubuntu 24.04 LTS (64-bit)
- **Expansion HAT**: Sunfounder Fusion HAT+ (PWM, WS2812, I2C, I2S audio)
- **AI Accelerator**: Hailo AI Kit (26 TOPS, PCIe interface)
- **Deployment Model**: Self-contained mobile robot, no external servers
- **Network Requirements**: Home WiFi (2.4/5GHz) for cloud API access only

**Key Infrastructure Services:**
- **Local AI Inference**: Hailo-accelerated Whisper STT (~150-200ms latency)
- **Cloud AI Services**: Anthropic Claude API (V1), OpenAI GPT-4 API (future)
- **Database**: SQLite (embedded, conversation history + config)
- **OTA Server**: HTTP server on Pi (Flask/FastAPI) serving firmware binaries
- **Real-Time Communication**: I2C bus (400kHz-1MHz) for ESP32 coordination
- **Servo Communication**: USB serial via Waveshare Bus Servo Adapters

**Deployment Host and Regions**: Local (Raspberry Pi), no cloud hosting. WiFi for API calls only.

## Repository Structure

**Structure:** Monorepo

**Monorepo Tool:** Git (no specialized monorepo tool needed for this scale)

**Organization Principle:** Module-first architecture with hybrid control topology. ESP32 modules (Head, Base) contain firmware for real-time tasks, while Pi-controlled modules (Neck, Ears, Indicator) are driver-only packages managed directly via Fusion HAT interfaces.

```
olaf/
├── modules/                    # All 5 modules (physical subsystems)
│   ├── head/                   # Head Module (I2C 0x10) - ESP32
│   │   ├── firmware/           # ESP32 firmware
│   │   │   ├── src/            # Source files (main.cpp, drivers/)
│   │   │   ├── include/        # Header files
│   │   │   ├── test/           # Unit tests
│   │   │   └── platformio.ini  # Build configuration
│   │   ├── hardware/           # Physical designs
│   │   │   ├── mechanical/     # 3D models (STEP, STL)
│   │   │   └── bom.csv         # Bill of materials
│   │   ├── tests/              # Module-specific integration tests
│   │   ├── diagnostics/        # Diagnostic tools (eyes)
│   │   ├── scripts/            # Build, flash, calibrate scripts
│   │   ├── wiring.md           # Pin assignments, circuits
│   │   ├── assembly.md         # Assembly instructions
│   │   └── README.md           # Module overview
│   │
│   ├── base/                   # Base Module (I2C 0x11) - ESP32
│   │   ├── firmware/           # ESP32 firmware
│   │   │   ├── src/            # main.cpp, imu.cpp, odrive.cpp
│   │   │   ├── include/        # Header files
│   │   │   ├── test/           # Unit tests
│   │   │   └── platformio.ini  # Build configuration
│   │   ├── hardware/           # Physical designs
│   │   │   ├── mechanical/     # 3D models (wheels, frame)
│   │   │   └── bom.csv         # Bill of materials
│   │   ├── tests/              # Module-specific integration tests
│   │   ├── diagnostics/        # Diagnostic tools (balance, motors)
│   │   ├── scripts/            # Build, flash, calibrate scripts
│   │   ├── wiring.md           # Pin assignments, circuits
│   │   ├── assembly.md         # Assembly instructions
│   │   └── README.md           # Module overview
│   │
│   ├── neck/                   # Neck Module - Pi-controlled (USB serial)
│   │   ├── hardware/           # Physical designs
│   │   │   ├── mechanical/     # 3D models (neck mechanism)
│   │   │   └── bom.csv         # Bill of materials (3× STS3215)
│   │   ├── tests/              # Module-specific integration tests
│   │   ├── diagnostics/        # Diagnostic tools (servo test)
│   │   ├── scripts/            # Calibration scripts
│   │   ├── assembly.md         # Assembly instructions
│   │   └── README.md           # Module overview
│   │
│   ├── ears/                   # Ears Module - Pi-controlled (USB serial)
│   │   ├── hardware/           # Physical designs
│   │   │   ├── mechanical/     # 3D models (ear mechanisms)
│   │   │   └── bom.csv         # Bill of materials (4× SCS0009)
│   │   ├── tests/              # Module-specific integration tests
│   │   ├── diagnostics/        # Diagnostic tools (servo test)
│   │   ├── scripts/            # Calibration scripts
│   │   ├── assembly.md         # Assembly instructions
│   │   └── README.md           # Module overview
│   │
│   ├── indicator/              # Indicator Module - Pi-controlled (WS2812)
│   │   ├── hardware/           # Physical designs
│   │   │   ├── mechanical/     # 3D models (LED strip mounts)
│   │   │   └── bom.csv         # Bill of materials (3× 8-LED strips)
│   │   ├── tests/              # Module-specific tests
│   │   ├── diagnostics/        # LED test patterns
│   │   └── README.md           # Module overview
│   │
│   └── shared/                 # Shared across modules
│       ├── firmware/           # Shared firmware libraries
│       │   ├── i2c-protocol/   # Common I2C register definitions
│       │   ├── ota/            # OTA update handlers
│       │   └── utils/          # Math, filters, utilities
│       └── hardware/           # Shared hardware components
│           ├── symbols/        # KiCad symbols library
│           ├── footprints/     # KiCad footprints
│           └── parts/          # Common 3D parts
│
├── ros2/                       # ROS2 workspace (Orchestration Layer)
│   └── src/                    # ROS2 packages source
│       ├── olaf_bringup/       # Launch files, configs
│       ├── olaf_description/   # URDF, robot models
│       ├── olaf_drivers/       # Hardware driver nodes
│       │   ├── olaf_head/      # I2C driver → Head ESP32 (eyes)
│       │   ├── olaf_base/      # I2C driver → Base ESP32 (motors, IMU)
│       │   ├── olaf_neck/      # USB serial → Waveshare (neck servos)
│       │   ├── olaf_ears/      # USB serial → Waveshare (ear servos)
│       │   └── olaf_indicator/ # Fusion HAT → WS2812 (LED strips)
│       ├── olaf_personality/   # Personality coordination
│       ├── olaf_ai/            # AI integration (Whisper, agents)
│       └── olaf_navigation/    # SLAM, navigation stack
│
├── scripts/                    # System-wide automation
│   ├── setup/                  # Environment setup
│   ├── build/                  # Build all modules
│   ├── flash/                  # Flash ESP32 modules
│   ├── test/                   # Test all modules
│   └── deploy/                 # OTA deployment
│
├── tools/                      # System-wide tools
│   ├── diagnostics/            # System diagnostics (i2c_scanner, system_health)
│   ├── calibration/            # Cross-module calibration
│   ├── simulators/             # I2C module simulators
│   └── utils/                  # General utilities (log analyzer)
│
├── tests/                      # System-wide integration tests
│   ├── integration/            # Cross-module tests (personality sync, navigation)
│   └── fixtures/               # Test fixtures, mock data
│
├── config/                     # System configuration
│   ├── i2c/                    # I2C bus configuration (Head 0x10, Base 0x11)
│   ├── ros2/                   # ROS2 parameters
│   ├── servo/                  # Servo calibration (neck, ears)
│   └── firmware/               # Firmware configs (WiFi, OTA)
│
├── docs/                       # System-level documentation
│   ├── architecture.md         # System architecture (this document)
│   ├── brief.md                # Project brief
│   ├── prd/                    # Product requirements (sharded)
│   ├── guides/                 # Build guides, tutorials
│   ├── api/                    # API references (I2C, ROS2, USB serial)
│   └── media/                  # Images, diagrams, videos
│
├── hardware/                   # System-level hardware only
│   ├── power/                  # Power distribution (buck converters)
│   └── enclosure/              # Main body/torso housing Pi + HATs
│
├── archive/                    # Previous iterations (gitignored)
├── .bmad-core/                 # BMAD agent configuration (gitignored)
├── .claude/                    # Claude Code settings (gitignored)
│
├── Makefile                    # Top-level build orchestration
├── pyproject.toml              # Python dependencies (ROS2)
├── poetry.lock                 # Poetry lockfile (gitignored)
├── .gitignore                  # Git ignore rules
├── LICENSE                     # MIT License
└── README.md                   # Main project README
```

**Module Responsibilities:**

| Module | Controller | Interface | Hardware |
|---|---|---|---|
| **Head (0x10)** | ESP32 | I2C | 2× OLED eyes (GC9A01, SPI) |
| **Base (0x11)** | ESP32 | I2C | ODrive (UART), BNO085 (I2C), self-balancing PID |
| **Neck** | Pi direct | USB Serial (Waveshare) | 3× STS3215 servos (pan/tilt/roll) |
| **Ears** | Pi direct | USB Serial (Waveshare) | 4× SCS0009 servos (2-DOF × 2 ears) |
| **Indicator** | Pi direct | Fusion HAT WS2812 | 24 LEDs (3× 8-LED strips) |

**Additional Pi-Controlled Hardware:**
- **Heart Display:** 4" Pi display (SPI) — animated heart, status
- **Kickstand:** 2× landing gear servos (4.8-7.4V) via Fusion HAT PWM
- **Speaker:** I2S via Fusion HAT audio
- **AI:** Hailo AI HAT (26 TOPS) for Whisper STT

**Key Organizational Benefits:**
- **Reduced Complexity:** Only 2 ESP32 modules to flash/debug (Head, Base)
- **No Soldering Required:** Fusion HAT provides pre-built interfaces for servos, LEDs, PWM
- **True Modularity:** ESP32 modules self-contained (firmware + hardware + tests)
- **Clear Ownership:** Pi-controlled modules are ROS2 packages only (no firmware)
- **Simplified Wiring:** USB cables for servos, single data line for WS2812
- **Matches Architecture:** Code structure mirrors the 5-module hybrid control topology

## High Level Architecture Diagram

```
┌─────────────────────────────────────────────────────────────────┐
│              INTELLIGENCE LAYER (Hybrid AI)                     │
│  Local: Whisper STT (Hailo) | Cloud: Agent (Claude/GPT-4)      │
│  • Speech Recognition (Hailo-accelerated, local <200ms)         │
│  • Agent Reasoning & Tool Use (cloud, WiFi)                     │
│  • Multi-step Planning & Context Management                     │
└──────────────────────┬──────────────────────────────────────────┘
                       │
                       │ HTTPS/REST (WiFi - Cloud Only)
                       │
┌──────────────────────▼──────────────────────────────────────────┐
│       ORCHESTRATION LAYER (Pi 5 + Fusion HAT+ + AI HAT)         │
│                   Powered by 2000mAh 7.4V Battery               │
│  ┌────────────────────────────────────────────────────────────┐ │
│  │ RASPBERRY PI 5 16GB (Ubuntu 24.04)                         │ │
│  │  • ROS2 Jazzy (5 driver nodes)                             │ │
│  │  • Personality Coordination  • State Management            │ │
│  │  • SLAM Navigation          • AI Integration               │ │
│  │  • I2C Master (GPIO2/3)     • OTA Server                   │ │
│  └────────────────────────────────────────────────────────────┘ │
│  ┌─────────────────┐ ┌─────────────────┐ ┌──────────────────┐   │
│  │ FUSION HAT+     │ │ AI HAT (Hailo)  │ │ 4" HEART DISPLAY │   │
│  │ • WS2812 port   │ │ • 26 TOPS       │ │ • Animated heart │   │
│  │ • PWM (P0-P3)   │ │ • Whisper STT   │ │ • Status info    │   │
│  │ • I2C bridge    │ │ • Vision models │ │ • SPI from Pi    │   │
│  │ • I2S speaker   │ └─────────────────┘ └──────────────────┘   │
│  └────────┬────────┘                                            │
│           │                                                      │
└───┬───────┼───────┬─────────────────┬───────────────────────────┘
    │       │       │                 │
    │I2C    │PWM    │USB ×2           │WS2812
    │       │       │                 │Data
┌───▼───┐ ┌─▼─────┐ │           ┌─────▼─────────────────────────┐
│ HEAD  │ │KICK-  │ │           │     WS2812 INDICATOR STRIP    │
│ ESP32 │ │STAND  │ │           │     (24 LEDs, 3×8 daisy)      │
│ 0x10  │ │2×Servo│ │           │  ┌────────┬────────┬────────┐ │
└───┬───┘ │4.8-7.4V│ │          │  │Strip 1 │Strip 2 │Strip 3 │ │
    │     │(at base)│ │          │  │Interact│Status  │PID     │ │
┌───▼───┐ └────────┘ │           │  │8 LEDs  │8 LEDs  │8 LEDs  │ │
│2×OLED │             │           └──┴────────┴────────┴────────┘ │
│Eyes   │             │
│SPI    │       ┌─────┴─────────────────────────────┐
└───────┘       │                                   │
                ▼                                   ▼
    ┌───────────────────────┐         ┌───────────────────────┐
    │ WAVESHARE BUS SERVO   │         │ WAVESHARE BUS SERVO   │
    │ ADAPTER (A) - NECK    │         │ ADAPTER (A) - EARS    │
    │ USB Serial            │         │ USB Serial            │
    └───────────┬───────────┘         └───────────┬───────────┘
                │                                 │
    ┌───────────▼───────────┐         ┌───────────▼───────────┐
    │ NECK SERVOS           │         │ EAR SERVOS            │
    │ 3× Feetech STS3215    │         │ 4× Feetech SCS0009    │
    │ Pan / Tilt / Roll     │         │ 2-DOF × 2 ears        │
    │ 30 kg·cm torque       │         │ Daisy-chained         │
    └───────────────────────┘         └───────────────────────┘

┌─────────────────────────────────────────────────────────────────┐
│                    I2C BUS (GPIO2 SDA, GPIO3 SCL)               │
└────────────────────────┬────────────────────────────────────────┘
                         │
         ┌───────────────┴───────────────┐
         │                               │
    ┌────▼────┐                     ┌────▼────┐
    │  HEAD   │                     │  BASE   │
    │  ESP32  │                     │  ESP32  │
    │  0x10   │                     │  0x11   │
    └────┬────┘                     └────┬────┘
         │                               │
    ┌────▼────────────┐         ┌────────▼────────────────────┐
    │ 2× OLED EYES    │         │ MOTOR & BALANCE SYSTEM      │
    │ 128×64, SPI     │         │ ┌─────────┐ ┌─────────────┐ │
    │ 30-60 FPS       │         │ │ BNO085 │ │ ODrive v3.6 │ │
    │ GC9A01 driver   │         │ │ IMU     │ │ UART        │ │
    │ Eye animations  │         │ │ 200Hz   │ │ 2× BLDC     │ │
    └─────────────────┘         │ └─────────┘ └─────────────┘ │
                                └─────────────────────────────┘
```

### Power Distribution

```
┌─────────────────────────────────────────────────────────────────┐
│              36V HOVERBOARD BATTERY (Charging Port A)           │
└────────┬────────────────────┬────────────────────┬──────────────┘
         │                    │                    │
         │ 36V Direct         │ 36V→12V Buck       │ 36V→5V Buck
         │                    │                    │
    ┌────▼────┐         ┌─────▼─────┐        ┌─────▼─────────────┐
    │ ODrive  │         │ SERVOS    │        │ ESP32s + OLED     │
    │ + BLDC  │         │ Neck ×3   │        │ • Head ESP32      │
    │ Motors  │         │ Ears ×4   │        │ • Base ESP32      │
    │         │         │ (12V in)  │        │ • 2× OLED eyes    │
    └─────────┘         └───────────┘        └───────────────────┘

┌─────────────────────────────────────────────────────────────────┐
│          2000mAh 7.4V BATTERY (Fusion HAT, Charging Port B)     │
└─────────────────────────────┬───────────────────────────────────┘
                              │
                    ┌─────────▼─────────┐
                    │ LOGIC SYSTEM      │
                    │ • Raspberry Pi 5  │
                    │ • Fusion HAT+     │
                    │ • AI HAT (Hailo)  │
                    │ • 4" Heart Display│
                    │ • WS2812 (24 LED) │
                    │ • Kickstand ×2    │
                    └───────────────────┘
```

### Communication Protocols

```
━━━━━━━━ I2C: Pi ↔ 2× ESP32 (Head 0x10, Base 0x11) - 5-20ms latency
─ ─ ─ ─  USB Serial: Pi ↔ 2× Waveshare Adapters (Neck, Ears servos)
- - - -  WiFi: Pi → Cloud AI APIs only (Claude/GPT-4)
━ ━ ━ ━  SPI: Head ESP32 → OLED displays (high-speed graphics)
━·━·━·━  UART: Base ESP32 → ODrive (motor commands, odometry)
────────  WS2812: Pi Fusion HAT → 24 LED strip (single data line)
─·─·─·─  PWM: Pi Fusion HAT → Kickstand servos (long wire to base)
```

### ROS2 Node Topology

```
┌─────────────────────────────────────────────────────────────────┐
│                    ROS2 JAZZY (on Pi 5 / Ubuntu 24.04)          │
│                                                                 │
│  ┌──────────────┐  ┌──────────────┐  ┌───────────────────────┐  │
│  │ olaf_head    │  │ olaf_base    │  │ olaf_indicator        │  │
│  │ I2C → 0x10   │  │ I2C → 0x11   │  │ HAT WS2812            │  │
│  │              │  │              │  │                       │  │
│  │ /head/expr   │  │ /cmd_vel     │  │ /indicator/interact   │  │
│  │ /head/blink  │  │ /odom        │  │ /indicator/status     │  │
│  │ /head/look   │  │ /imu         │  │ /indicator/pid        │  │
│  └──────────────┘  └──────────────┘  └───────────────────────┘  │
│                                                                 │
│  ┌──────────────┐  ┌──────────────┐  ┌───────────────────────┐  │
│  │ olaf_neck    │  │ olaf_ears    │  │ olaf_personality      │  │
│  │ USB Serial   │  │ USB Serial   │  │ AI Integration        │  │
│  │              │  │              │  │                       │  │
│  │ /neck/pose   │  │ /ears/emote  │  │ /speech/text          │  │
│  │ /neck/lookat │  │ /ears/perk   │  │ /ai/response          │  │
│  └──────────────┘  └──────────────┘  └───────────────────────┘  │
│                                                                 │
└─────────────────────────────────────────────────────────────────┘
```

## Architectural Patterns

- **Layered Architecture (Intelligence → Orchestration → Module)**: Separates high-level reasoning (AI agents) from real-time control (ESP32 firmware) and direct hardware control (Pi via Fusion HAT), enabling independent development and testing. _Rationale: Matches robotics best practices, clear responsibility boundaries._

- **Hybrid Control Topology (ESP32 + Pi Direct)**: Real-time critical tasks (eye animations at 60 FPS, self-balancing at 200Hz) run on dedicated ESP32 controllers, while latency-tolerant hardware (servos, LEDs, kickstand) is controlled directly by Pi via Fusion HAT and USB adapters. _Rationale: Minimizes ESP32 count (4→2), eliminates soldering, leverages pre-built interfaces while preserving real-time guarantees where needed._

- **Smart Peripheral Pattern (I2C Slaves with Embedded Intelligence)**: Head and Base ESP32 modules act as smart controllers containing full hardware drivers, animation engines, and real-time control loops (200Hz self-balancing on Base, 60 FPS eye rendering on Head), receiving only high-level semantic commands from Pi via I2C. _Rationale: Offloads real-time tasks from Linux-based Pi, reduces I2C traffic, enables autonomous execution._

- **Direct HAT Control Pattern (Pi-Controlled Peripherals)**: Neck servos, ear servos, indicator LEDs, and kickstand are controlled directly by Pi through Fusion HAT interfaces (USB serial for Waveshare adapters, WS2812 data line for LEDs, PWM for kickstand servos). ROS2 nodes manage these peripherals without intermediate microcontrollers. _Rationale: Eliminates unnecessary ESP32s, simplifies wiring (USB cables vs. custom PCBs), reduces firmware maintenance burden._

- **Hardware Abstraction via Driver Nodes**: ROS2 driver nodes on Pi translate between ROS2 topics (semantic) and hardware interfaces (I2C registers for ESP32s, USB serial for Waveshare adapters, HAT APIs for LEDs/PWM), isolating hardware details from application logic. _Rationale: Modules replaceable without changing high-level code, standard robotics pattern._

- **Hybrid AI Processing (Local Fast-Path + Cloud Reasoning)**: Hailo accelerator handles time-sensitive inference (Whisper STT) locally, while complex reasoning offloads to cloud LLMs. _Rationale: Balances latency (<3s requirement) with AI capability (GPT-4 quality personality)._

- **Event-Driven Communication (ROS2 Pub/Sub)**: Asynchronous message passing between ROS2 nodes enables loose coupling. ESP32 modules use interrupt-driven I2C to minimize latency. _Rationale: Responsive (<500ms expression sync), power-efficient, decouples producers/consumers._

- **Repository Pattern (Conversation & Config Storage)**: SQLite abstraction layer for data persistence, encapsulates queries. _Rationale: Testable without database, future migration to cloud storage possible._

- **Reduced Firmware Footprint (2 ESP32 Modules Only)**: Only Head (eyes) and Base (balancing) require dedicated ESP32 firmware. All other hardware managed by Pi ROS2 nodes. _Rationale: Fewer firmware projects to maintain, faster iteration, reduced OTA complexity._

- **Autonomous Real-Time Control Pattern (Base Self-Balancing)**: Critical timing loops (200Hz PID balancing) run entirely on Base ESP32 with hardware timers, Pi sends only abstract navigation commands. _Rationale: Linux cannot guarantee real-time deadlines, ESP32 FreeRTOS provides hard real-time guarantees essential for stability._

- **Dual Battery Isolation (Power + Logic)**: 36V hoverboard battery powers high-current systems (motors, servos, ESP32s) via buck converters, while dedicated 2000mAh 7.4V battery powers logic systems (Pi, HATs, display, LEDs) via Fusion HAT. _Rationale: Isolates sensitive electronics from motor noise, enables independent charging, prevents brownouts during motor startup._

---

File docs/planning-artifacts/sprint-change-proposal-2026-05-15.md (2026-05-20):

# Sprint Change Proposal — Expression Engine Re-scope

**Date:** 2026-05-15
**Author:** Kamal Singh (with PM agent — John)
**Status:** Draft — awaiting approval
**Trigger type:** Necessary pivot based on new external contract
**Change-checklist:** `.bmad-core/checklists/change-checklist.md` (Sections 1–6, worked incrementally)

> **Terminology.** "Avatar" = the whole OLAF robot/project (OLAF *is* an avatar). The component built here is the **expression engine** — ROS package `expression_engine`. We do not use "embodiment" as our vocabulary; the companion's external doc keeps its own filename `olaf-embodiment-brief.md` (their file), quoted literally only.

---

## 1. Identified Issue Summary

The sibling project `olaf_companion` finalized its publisher contract at `schema_version=3` on 2026-05-10. That work (the `olaf-embodiment-brief.md` plus the companion's own sprint-change-proposal-2026-05-10) **moved the renderer mapping out of the publisher and onto the body's side**, and collapsed everything the AI agent communicates to the body into **four typed ROS 2 topics**:

- `mood` — slow disposition (≤4/hour, latched)
- `activity` — 7-state FSM (latched)
- `speech_emotion` — per-segment, audio-anchored ~30–80ms anticipatory
- `vocalization` — punctual audio-bursts + gesture cues (`nod`/`shake`)

The OLAF body repo's pre-existing Phase 2-shaped scaffolding was sketched **before** this contract existed and is now misaligned:

- `olaf_interfaces/msg/Expression.msg` — a 7-emotion enum incompatible with the companion's 12 canonical first-class emotions, 8 moods, 7 activity states, 6 vocalizations.
- `Gesture.msg`, `EarsPose.msg`, `HeartRate.msg` — raw-angle / per-module public surfaces, superseded by a body-side `expression_map.yaml` + in-process driver calls.
- `ros2/src/olaf_personality/` — empty directory placeholder for the rendering coordinator.
- `architecture/` docs place "Personality Coordination" and "Hybrid AI Processing" on this Pi; those responsibilities now live in `olaf_companion`. This repo is the **expression engine**: subscribe, map, render.

**Core problem stated plainly:** the body's external interface was designed per-module and pre-contract. The contract is now stable and consumer-agnostic. The body must converge on *subscribe-only to 4 canonical topics, with all rendering decisions as body-side data*.

Crucially: **Phase 1 is not the problem.** Phase 1's NFR3 explicitly deferred AI/personality to Phase 2. Everything being archived is Phase 2 scaffolding that was never wired into anything. The hardware, drivers, firmware, configs, and calibration that Phase 1 delivered are exactly the "components we have built" to reuse.

### Evidence

- `olaf_companion/.../planning-artifacts/olaf-embodiment-brief.md` (2026-05-10) — defines the wire and the consumer-agnostic boundary.
- Companion's `sprint-change-proposal-2026-05-10.md` — records the mapping moving out of the publisher (schema 2→3).
- `ros2/src/olaf_interfaces/msg/Expression.msg` — 7-enum, demonstrably incompatible with the 12 canonical names.
- `ros2/src/olaf_personality/` — empty (not even a package skeleton); confirms zero sunk code, low pivot cost.

---

## 2. Epic Impact Summary

### Phase 1 — all epics survive untouched

| Epic (implied by story prefix) | Stories | Impact |
|---|---|---|
| Epic 0 — Dev environment | 0.1–0.7 | None |
| Epic 1 — Head module (eyes) | 1.3, 1.4 | None — driver reused in-process |
| Epic 2 — Base module (locomotion/balancing) | 2.4–2.8 | **Out of scope** — orthogonal ESP32 firmware track, stays as-is |
| Epic 3 — Neck module | 3.1, 3.4 | None — driver reused |
| Epic 4 — Ears module | 4.1–4.4 | None — driver reused |

### Phase 2 — abandoned-as-sketched, replaced by four new epics

The implicit per-module Phase 2 surface (the four msgs + empty `olaf_personality` + "personality coordination on Pi") is **abandoned in its current form**. Replacement structure, all under a new `docs/prd/phase2-prd.md`:

| Epic | Value delivered | Blocks |
|---|---|---|
| **Epic 5 — Restructure & driver verification** *(gate)* | Clean foundation; every reused driver proven on real hardware. Nothing downstream starts until green. | 6, 7, 8 |
| **Epic 6 — Expression engine** | A working engine: canonical events in → expression out, and never statue-still when idle. | — |
| **Epic 7 — Expression authoring & finalization** | The full emotional vocabulary, tuned and regression-locked. | — |
| **Epic 8 — Heart display animation** | Secondary surface adds to aliveness, after core body language is locked. | — |

**Sequencing:** Epic 5 (gate) → Epic 6 → Epic 7 → Epic 8, strictly in order. No dependency on companion *implementation* — develop against the schema with a mock publisher.

#### Epic 5 — Restructure & driver verification (gate)

| Story | Scope |
|---|---|
| 5.1 | Execute archival/delete/rename/scaffold per §4 (move 4 msgs to `archive/`, delete empty `olaf_personality/`, scaffold `expression_engine`, edit CMakeLists). |
| 5.2 | Doc edits per §4 (architecture diagram, patterns, technical-summary, repository-structure, Phase 1 PRD change-log, README). |
| 5.3 | Per-driver hardware verification: neck, ears, head/eye drivers each move real hardware via a standalone test script (Phase 1 component-test convention). Gate is green only when all pass. |

#### Epic 6 — Expression engine

| Story | Scope |
|---|---|
| 6.1 | Subscriber on the 4 topics + schema-3 `EventEnvelope` validation; fail-fast (raise, exit non-zero, journald) on `schema_version != 3`. |
| 6.2 | `expression_map.yaml` schema + loader + vocabulary-completeness check (strict against the pinned companion release; runtime-graceful — see §3). |
| 6.3 | Animation loop: fixed render tick, easing curves, the 30–80ms anticipatory window, gesture attack/settle. |
| 6.4 | One hand-authored **reference expression** rendered end-to-end (e.g. `speech_emotion=happy` → servos+eyes) — proves and **freezes the schema** for Epic 7. |
| 6.5 | Idle behavior: idle FSM (sleeping vs listening-and-silent), micro-movement, return-to-mood-neutral after 3s of `speech_emotion` silence. |
| 6.6 | Real WS2812 LED adapter + breath-LED (first real LED use; infrastructure reused by Epic 7). |
| 6.7 | systemd unit, structured JSON logging, startup validation order (config → map → DDS → adapters → running). |

#### Epic 7 — Expression authoring & finalization

| Story | Scope |
|---|---|
| 7.1 | Author + finalize the 12 **speech-emotions** — the primary expression layer, the bulk of the work. |
| 7.2 | Author + finalize the 6 **vocalizations**, including **actions layered on top of base poses** (`[nod]`/`[shake]` composed over a base pose). |
| 7.3 | **Activity → posture mapping** — simple, one posture per state. |
| 7.4 | **Mood → subtle ambient modifier** — lightweight; low direct impact on expression (small LED/lean bias only). |
| 7.5 | Locked-expression **regression harness** — replay events, assert pose/LED/eye output, prevent drift as the vocabulary grows. |

#### Epic 8 — Heart display animation

| Story | Scope |
|---|---|
| 8.1 | Mood/activity-driven heart rendering on the 4" Pi display, engine-owned (replaces retired `HeartRate.msg`). |

---

## 3. Extensible Vocabulary — Design Principle

The expression vocabulary **will grow over time**. The companion brief makes vocabulary completeness a startup blocker; this principle reconciles strictness with growth and becomes a Phase 2 NFR:

1. **Startup-strict against the pinned companion release.** The loader validates `expression_map.yaml` covers the canonical set *of the pinned `olaf_companion` tag* — complete-for-this-version, not complete-forever.
2. **Growth is a pure data edit.** Adding an expression is a new block in `expression_map.yaml`; the engine is vocabulary-agnostic and never needs a code change to learn a new name.
3. **Runtime grace.** An unknown name (companion ran ahead of our map) logs `expression.unmapped_<topic>` at WARN and falls back to a `default_*` pose — the body never freezes (companion brief §Risks).
4. **Lockstep for known growth.** When companion adds expressions and bumps schema, we extend the map and re-pin the companion tag in the *same* change.

---

## 4. Artifact Adjustment Needs

### Archive (move to `archive/`, removed from active build, preserved in git)

| Artifact | Reason |
|---|---|
| `ros2/src/olaf_interfaces/msg/Expression.msg` | Replaced by canonical 12-emotion / 8-mood vocabulary, body-side mapping |
| `ros2/src/olaf_interfaces/msg/Gesture.msg` | Raw-angle public surface; engine uses driver Python APIs in-process |
| `ros2/src/olaf_interfaces/msg/EarsPose.msg` | Same as Gesture |
| `ros2/src/olaf_interfaces/msg/HeartRate.msg` | Replaced by mood/activity-driven heart animation (Epic 8) |

Moved to `archive/ros2/olaf_interfaces/msg/` with a `README.md` explaining the supersession (points to this proposal). `ModuleStatus.msg` is **kept** — health monitoring is orthogonal to expression.

Two ROS-node wrappers were coupled to these msgs and are archived alongside (they *are* the retired per-module surface — see the three-layer split below):

| Artifact | Reason |
|---|---|
| `ros2/src/olaf_drivers/head_ears_driver/head_ears_driver/ears_node.py` | Subscribed to `/olaf/ears/expression`+`/olaf/ears/pose` (archived msgs) |
| `ros2/src/olaf_drivers/head_ears_driver/head_ears_driver/head_node.py` | Same per-module subscriber pattern |
| `ros2/src/olaf_bringup/launch/ears.launch.py` | Launched the now-removed `ears_node` executable |

Moved to `archive/ros2/olaf_drivers/head_ears_driver/` and `archive/ros2/olaf_bringup/launch/` with a `README.md`. `head_ears_driver`'s `console_scripts` entry points were emptied accordingly.

### Delete

`ros2/src/olaf_personality/` — empty directory, superseded by the new `expression_engine` package.

### Edit (substantive doc/code changes)

| Artifact | Change |
|---|---|
| `docs/prd/phase1-prd.md` | Add change-log entry (v2.1): "Phase 2 redirected to consume canonical 4-topic contract from `olaf_companion`; see `docs/prd/phase2-prd.md`." Update NFR3 to point to the new Phase 2 PRD by name. No body deletions. |
| `docs/architecture/high-level-architecture-diagram.md` | In the Pi block, replace "Personality Coordination / AI Integration" bullets with "Expression Engine (subscribes to `olaf_companion`)" + "Driver Nodes". Add a publisher block above showing `olaf_companion` and the 4 typed topics as the wire. |
| `docs/architecture/architectural-patterns.md` | Replace "Hybrid AI Processing (Local Fast-Path + Cloud Reasoning)" with an "Expression Engine Pattern (Subscribe-only renderer of canonical events)" entry. Add a caveat to "Hardware Abstraction via Driver Nodes": drivers are consumed in-process by the engine; ROS topics retained as low-level inspection surface only. |
| `docs/architecture/technical-summary.md` | Same redirection (personality/AI now external). |
| `docs/architecture/repository-structure.md` | Document the new `expression_engine` package; remove `olaf_personality`. |
| `ros2/src/olaf_interfaces/CMakeLists.txt` | Remove the four archived msg entries; keep `ModuleStatus.msg`. |
| `ros2/src/olaf_bringup/launch/` | Add `expression_engine.launch.py` (drivers + `expression_engine_node`). |
| `README.md` (top-level) | Trim any "personality coordination / AI on Pi" framing so new contributors aren't misled. |

### New (authored after this proposal is approved)

- `docs/prd/phase2-prd.md` — the Phase 2 PRD (PM/Architect).
- Four epics (5/6/7/8) + their stories (SM).
- `ros2/src/expression_engine/` package (see §5 structure).
- `expression_map.yaml`, `expression_engine.toml` — starting points in companion brief Appendix B, living in `ros2/src/expression_engine/config/`.

### Driver packages — three-layer split (refinement)

The original "drivers untouched" line was too coarse. Inspecting `head_ears_driver` during Epic 5.1 showed each driver package mixes three layers; only one is retired:

| Layer | Files (head_ears_driver example) | Disposition |
|---|---|---|
| **Hardware logic** | `ears_servo_driver.py`, `head_i2c_client.py` | **Kept, untouched.** Imported in-process by the engine's adapters (Epic 6). |
| **Expression content** | `expressions.py` (emotion → ear-pose presets; `ears_demo.py` notes "12 Emotional States") | **Kept, becomes Epic 7 seed** for `expression_map.yaml` — Epic 7 adapts proven poses rather than authoring from blank. |
| **Retired skin** | `ears_node.py`, `head_node.py` (subscribe to archived msgs), `bringup/launch/ears.launch.py` | **Archived** — this is the per-module topic surface the pivot eliminates. |

### Untouched

All other `olaf_drivers/*` code (neck/base/torso drivers, calibration tools), all `modules/*/firmware` (incl. base balancing), all `config/*`, `libs/scservo_sdk`, Phase 1 PRD body, `phase1-tracking.md`, all completed stories 0.x–4.x, `scripts/`, `tools/`.

---

## 5. Target File Structure

```
ros2/src/expression_engine/      # NEW package (no olaf_ prefix — project is OLAF)
├── package.xml                  # deps: rclpy, olaf_interfaces, driver pkgs
├── setup.py                     # entry_point: expression_engine_node = expression_engine.node:main
├── setup.cfg
├── resource/expression_engine
├── config/
│   ├── expression_map.yaml      # mood/activity/emotion/vocalization → pose/LED/eye/heart
│   └── expression_engine.toml   # DDS domain, topic names, anim timings, idle params
├── expression_engine/
│   ├── __init__.py
│   ├── node.py                  # ROS2 node: wires subscribers → render loop
│   ├── schema.py                # schema-3 EventEnvelope + 4 payload models, fail-fast
│   ├── subscribers.py           # 4 topic subs
│   ├── map_loader.py            # loads + validates expression_map.yaml vs pinned vocab
│   ├── render_loop.py           # fixed-tick loop, easing, anticipatory window
│   ├── idle.py                  # idle FSM: micro-move, breath-LED, return-to-neutral
│   └── adapters/
│       ├── base.py              # Adapter Protocols (servo/eye/led/heart)
│       ├── neck_adapter.py      # imports neck_driver         [real, Epic 6]
│       ├── ears_adapter.py      # imports head_ears_driver     [real, Epic 6]
│       ├── eye_adapter.py       # imports head_ears_driver     [real, Epic 6]
│       ├── led_adapter.py       # WS2812 direct, engine-owned   [real, Epic 6.6]
│       └── heart_adapter.py     # 4" Pi display, engine-owned   [stub→real, Epic 8]
└── test/
    ├── test_schema.py
    ├── test_map_loader.py
    ├── test_locked_expressions.py   # regression harness (Epic 7.5)
    └── mock_publisher.py            # fake companion driving all 4 topics for dev/CI

archive/ros2/olaf_interfaces/msg/
├── Expression.msg  Gesture.msg  EarsPose.msg  HeartRate.msg
└── README.md                    # supersession note → this proposal

ros2/src/olaf_interfaces/msg/ModuleStatus.msg     # KEPT
ros2/src/olaf_drivers/*                           # UNTOUCHED, imported in-process
ros2/src/olaf_personality/                        # DELETED (empty)
docs/prd/phase2-prd.md                            # NEW
```

---

## 6. Recommended Path Forward

**Option 3 — Re-scope** (selected over Direct-Adjustment and Rollback).

- **Direct Adjustment** rejected: carrying zombie msg types between the wire and the actuators dilutes the brief's strongest invariant ("mapping is data, body-side, keyed on canonical names") and confuses future contributors.
- **Rollback** rejected: the issue is design-level, not commit-level; `git revert` adds history noise without resolving the conceptual ambiguity.
- **Re-scope** chosen: matches the companion brief's intent, reuses every Phase 1 artifact, throws away ~4 unused files + 1 empty dir, produces a tractable four-epic Phase 2 plan. Lowest *delivery* risk because we are cutting paper, not code.

---

## 7. PRD MVP Impact

- **Phase 1 MVP:** unchanged.
- **Phase 2 MVP:** defined for the first time, not cut. Target (fleshed out in `phase2-prd.md`):
  - Subscribe + schema-3 validation + fail-fast on bad envelopes / wrong schema version.
  - `expression_map.yaml` covers the full canonical set of the pinned companion release (extensible per §3).
  - Servo/eye loop hits the 30–80ms anticipatory window (companion NFR5).
  - `[nod]`/`[shake]` land within ~150ms; crisp attack.
  - Idle return-to-mood-base after 3s of `speech_emotion` silence; never statue-still.
  - Hardware swap = one new Protocol adapter (brief Success Criteria).
  - Finalized expressions are regression-locked (Epic 7.5).

---

## 8. High-Level Action Plan & Agent Handoff

| Step | Owner | Action |
|---|---|---|
| 1 | **You** | Approve this proposal. |
| 2 | **PM/Architect** | Author `docs/prd/phase2-prd.md` anchored on the companion brief + this proposal. |
| 3 | **Architect** | Phase 2 architecture: engine node internals, Protocol adapter shapes, animation tick model, idle FSM. Incorporate brief Appendix B. |
| 4 | **SM** | Draft stories for Epics 5/6/7/8 from `phase2-prd.md`. Epic 5 first (it gates the rest). |
| 5 | **Dev** | Implement Epic 5 (restructure + driver verification gate) — must be green before Epic 6 starts. Then 6 → 7 → 8. |

### Validation — how we'll know the change worked

- Epic 5 gate green: every reused driver moves real hardware via its standalone test script.
- `ros2 topic list` on a running stack shows the expression engine subscribing to the 4 canonical topics and **no** legacy expression topics.
- The mock companion publisher driving schema-3 events produces visible, correctly-timed body expression.
- Startup fails loudly on an incomplete `expression_map.yaml` or a `schema_version != 3` event.
- Adding a new expression to `expression_map.yaml` requires **no code change** and the regression harness still passes.
- All Phase 1 component test scripts still pass unchanged (proof reused components were not regressed).

---

## 9. Decisions Captured (this session)

1. Naming: robot/project = "avatar"; the component = **expression engine**; package = `expression_engine` (no `olaf_` prefix).
2. Location: rebuild **inside this repo**.
3. Existing module topic surfaces: **retire all four**; engine imports driver Python modules directly, no intermediate ROS topics.
4. Archive scope: **architecture skin only** — keep all proven Phase 1 components.
5. Base-module balancing: **out of scope**, stays on its own ESP32 firmware track.
6. Epic structure: **four epics (5/6/7/8)**. Idle/aliveness and the LED adapter are *stories* inside Epic 6, not their own epic. Heart display is its own (last) epic.
7. Hard gate: Epic 5 (restructure complete + all drivers verified on hardware) **blocks** Epics 6–8.
8. Overlap resolution: Epic 6 includes one reference expression that **freezes the schema**; Epic 7 mass-authors against the frozen schema — no double work.
9. Missing LED/heart drivers: engine owns them directly; LED becomes real in Epic 6.6, heart in Epic 8 (stub before that).
10. Config location: inside the package — `ros2/src/expression_engine/config/`.
11. Vocabulary is **extensible** — strict against the pinned companion release, graceful at runtime, growth is a data edit (§3).
12. Authoring scope: no live tuner; mood is a low-impact subtle modifier; activity is a simple posture mapping.
13. Phase 2 PRD: `docs/prd/phase2-prd.md`.
14. Path: **Option 3 — Re-scope**.
15. Driver three-layer split (found during Epic 5.1 execution): hardware logic kept & imported in-process; `expressions.py` presets kept as Epic 7 seed; ROS-node wrappers (`ears_node.py`, `head_node.py`) + `ears.launch.py` archived as retired skin. All 7 ROS packages verified colcon-buildable post-restructure.

---

*This proposal lives in the OLAF body repo. Its companion-side counterpart is `olaf_companion/.../sprint-change-proposal-2026-05-10.md`. Keep schema-version assumptions pinned to a tagged release of `olaf_companion` — bump in lockstep.*

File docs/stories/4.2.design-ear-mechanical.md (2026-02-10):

# Story 4.2: Design Ear Mechanical Assembly

## Status: Done

## Story

**As a** builder,
**I want** ear mechanical design with 2-DOF per ear,
**so that** ears can express emotions through movement.

## Acceptance Criteria

1. OnShape CAD model for ear mounts and ear shapes
2. 2 servos per ear: base rotation + ear angle
3. Ear shapes suitable for robot aesthetic
4. Mounting points on head enclosure
5. STL files exported and parts printed

## Tasks / Subtasks

- [ ] Task 1: Design ear base mounts (AC: 1, 2)
  - [ ] Create OnShape document for ear assembly
  - [ ] Design base bracket for SCS0009 servo (ID 1 left, ID 3 right)
  - [ ] Design servo horn adapter for second servo mounting
  - [ ] Ensure base rotation axis perpendicular to head surface
  - [ ] Add cable routing channels for servo wires

- [ ] Task 2: Design ear angle mechanism (AC: 2)
  - [ ] Design second servo (ID 2 left, ID 4 right) mounting bracket
  - [ ] Create linkage between servo and ear
  - [ ] Ensure ear angle axis allows forward/back tilt
  - [ ] Define motion range: ±45° from neutral

- [ ] Task 3: Design ear shapes (AC: 3)
  - [ ] Design ear shape appropriate for robot aesthetic (cat/fox/custom)
  - [ ] Size ears proportionally to head (approximately 60-80mm tall)
  - [ ] Design ear attachment point to servo horn
  - [ ] Ensure ear is lightweight (<30g each) for servo capacity
  - [ ] Add internal structure for rigidity

- [ ] Task 4: Design head mounting interface (AC: 4)
  - [ ] Define mounting hole pattern on head enclosure top/sides
  - [ ] Design ear bracket flanges with screw holes
  - [ ] Ensure symmetric placement (left and right)
  - [ ] Allow cable routing from ears to inside head

- [ ] Task 5: Export and print (AC: 5)
  - [ ] Export all parts as STL files
  - [ ] Document print settings (layer height, infill, supports)
  - [ ] Print test parts and verify fitment
  - [ ] Iterate design if needed
  - [ ] Print final parts

- [ ] Task 6: Document assembly (AC: 1-5)
  - [ ] Create `modules/ears/assembly.md` with step-by-step instructions
  - [ ] Include BOM with screw sizes and quantities
  - [ ] Add photos or renders of assembly steps
  - [ ] Document servo cable routing

## Dev Notes

### Servo Specifications (SCS0009)

| Parameter | Value |
|---|---|
| Dimensions | 23 × 12.2 × 29mm |
| Weight | 9g |
| Torque | 1.6 kg·cm @ 6V |
| Speed | 0.09 sec/60° @ 6V |
| Rotation | 300° (continuous optional) |
| Voltage | 4.8-7.4V |

### Ear Motion Requirements

| Motion | Servo | Range | Example Expressions |
|---|---|---|---|
| Base rotation | ID 1, 3 | ±60° | Perked (forward), Alert (sides), Relaxed (back) |
| Ear angle | ID 2, 4 | ±45° | Happy (up), Sad (down), Curious (tilted) |

### Expression Presets

| Expression | Base Rotation | Ear Angle | Description |
|---|---|---|---|
| Neutral | 0° | 0° | Default resting position |
| Perked | +30° forward | +20° up | Alert, interested |
| Alert | +45° outward | 0° | Listening, scanning |
| Sad | -30° back | -30° down | Droopy, dejected |
| Happy | +20° forward | +30° up | Excited, joyful |
| Relaxed | -20° back | -10° down | Calm, resting |

### Design Guidelines

**Materials:**
- PLA or PETG for structural parts
- Consider flexible TPU for ear tips (optional)

**Print Settings (recommended):**
- Layer height: 0.2mm
- Infill: 20-30%
- Supports: Yes for overhangs >45°
- Walls: 3 perimeters

**Mechanical:**
- Use M2 or M2.5 screws for servo mounting
- Design for snap-fit where possible to reduce hardware
- Include clearance for wire routing
- Avoid tight tolerances (<0.2mm gap)

### Source Tree

```
modules/ears/
├── hardware/
│   ├── 3d-models/
│   │   ├── ear-base-mount-left.stl
│   │   ├── ear-base-mount-right.stl
│   │   ├── ear-angle-bracket.stl
│   │   ├── ear-shape-left.stl
│   │   └── ear-shape-right.stl
│   └── bom/
│       └── ears-bom.csv
├── assembly.md
└── README.md
```

### OnShape Project

- Create under: OLAF Project → Ears Module
- Use parametric design for adjustability
- Link to head enclosure for interface dimensions

### Testing

**Mechanical Tests:**
- Verify servo horn fits in mount
- Verify screw holes align
- Verify motion range without interference
- Verify ear weight is within servo capacity

**Print Tests:**
- Check dimensional accuracy (±0.3mm acceptable)
- Check layer adhesion for structural parts
- Check snap-fit connections work

## Change Log

| Date | Version | Description | Author |
|---|---|---|---|
| 2026-02-07 | 1.0 | Initial story creation for Epic 4 | Sarah (PO Agent) |
| 2026-02-10 | 1.1 | Marked Done — mechanical design and assembly completed by builder | Dev Agent (Claude Opus 4.6) |

---

## Dev Agent Record

### Agent Model Used
<!-- Record the specific AI agent model and version used for development -->

### Debug Log References
<!-- Reference any debug logs or traces generated during development -->

### Completion Notes List
<!-- Notes about the completion of tasks and any issues encountered -->

### File List
<!-- List all files created, modified, or affected during story implementation -->

---

## QA Results
<!-- Results from QA Agent review of the completed story implementation -->

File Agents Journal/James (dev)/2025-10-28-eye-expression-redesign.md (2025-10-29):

# Session Log: Eye Expression Redesign with chopsticks1 Inspiration
**Agent:** James (Dev Agent)
**Date:** 2025-10-28
**Session:** Evening
**Story:** 1.4 - Head Module ESP32 Firmware - Eye Expressions

## What I Was Trying to Do
Redesign OLAF's eye expressions using chopsticks1 face controller as inspiration - different shapes and colors per emotion instead of just size/position changes.

## What Happened

### Initial Redesign ✅
- Fetched chopsticks1 face.py code for inspiration
- Implemented 5 different eye shapes: rounded rects, circles, arcs (up/down), lines
- Added color coding: Cyan (neutral), Green (happy), Blue (sad), Orange (confused), White (excited)
- Created test scripts for Pi

### Iteration 1: Shape and Color Issues 🐛
Kamal: *"2 problem.. happy and sad faces does not have good shape.. the color is still cyan... and the blink duration range is too large"*

**Fixed:**
- Rewrote arc drawing functions with better elliptical curves
- Added proper color variety (was only setting color for EXCITED)
- Reduced blink duration: 180-250ms (was 180-320ms)

### Iteration 2: Blink Improvements 💡
Kamal: *"the closed eye shape is one horizontal line as it is now for confused.. the blink is still flikkery.. the one in chopsticks1 was not (i think their only few frames were used?)"*

**Key insight:** chopsticks1 used discrete frames, not continuous animation!

**Fixed:**
- Changed closed eye to thin curved lines (distinct from confused)
- Implemented discrete 4-frame blink: OPEN → HALF → CLOSED → HALF → OPEN
- Added frame change detection to skip redundant redraws
- Added blink-during-transition for natural expression changes

### Iteration 3: Transition Flicker 🐛
Kamal: *"worksing.. transition is flikkery though"*

**Fixed:**
- Changed transition to snap expression when eyes are closed
- No more continuous redrawing during interpolation
- Effect: "Close with old → Switch while closed → Open with new"

### Iteration 4: Stray Pixels 🐛
Kamal: *"now the oold expressions are not cleared fully and new expressions appear so there are lots of stry pixels"*

**Fixed:**
- Added expression change tracking in renderPupils()
- Force full screen clear when expression changes
- Increased clear margin from 8 to 20 pixels around eyes

## Final Result ✅
Kamal: *"great.. lets close for now"*

**Working features:**
- 5 eye shapes (rounded rects, circles, arcs up/down, lines)
- 5 colors (cyan, green, blue, orange, white)
- Smooth discrete-frame blinking (no flicker)
- Clean expression transitions
- No stray pixels

## Technical Details
- Discrete blink frames: 0.0, 0.4, 1.0, 0.4, 0.0
- Arc shapes use elliptical scanline rendering
- Expression snap happens at blink midpoint (0.4-0.6 progress)
- Clear margin: 20 pixels for thorough cleanup

## What I Learned
- Discrete frames > continuous animation for reducing flicker
- Transition animations need to happen while eyes are closed
- Screen clearing logic is critical for shape-changing animations
- User feedback iteration is key - initial "perfect" solution had 4 issues!

## Current Status
Story 1.4 expressions redesigned and working smoothly. Ready for integration testing.

**Files modified:** 11 files, ~2500 lines
**Commits:** 5 (redesign, arc fix, blink improvements, transition fix, cleanup fix)
**Test scripts created:** test_expressions.sh, i2c_test_commands.txt

---
*Session Duration: ~2 hours of iterative refinement* 🎉

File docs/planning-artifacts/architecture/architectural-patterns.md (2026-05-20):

# Architectural Patterns

- **Layered Architecture (Intelligence → Orchestration → Module)**: Separates high-level reasoning (AI agents) from real-time control (ESP32 firmware) and direct hardware control (Pi via Fusion HAT), enabling independent development and testing. _Rationale: Matches robotics best practices, clear responsibility boundaries._

- **Hybrid Control Topology (ESP32 + Pi Direct)**: Real-time critical tasks (eye animations at 60 FPS, self-balancing at 200Hz) run on dedicated ESP32 controllers, while latency-tolerant hardware (servos, LEDs, kickstand) is controlled directly by Pi via Fusion HAT and USB adapters. _Rationale: Minimizes ESP32 count (4→2), eliminates soldering, leverages pre-built interfaces while preserving real-time guarantees where needed._

- **Smart Peripheral Pattern (I2C Slaves with Embedded Intelligence)**: Head and Base ESP32 modules act as smart controllers containing full hardware drivers, animation engines, and real-time control loops (200Hz self-balancing on Base, 60 FPS eye rendering on Head), receiving only high-level semantic commands from Pi via I2C. _Rationale: Offloads real-time tasks from Linux-based Pi, reduces I2C traffic, enables autonomous execution._

- **Direct HAT Control Pattern (Pi-Controlled Peripherals)**: Neck servos, ear servos, indicator LEDs, and kickstand are controlled directly by Pi through Fusion HAT interfaces (USB serial for Waveshare adapters, WS2812 data line for LEDs, PWM for kickstand servos). ROS2 nodes manage these peripherals without intermediate microcontrollers. _Rationale: Eliminates unnecessary ESP32s, simplifies wiring (USB cables vs. custom PCBs), reduces firmware maintenance burden._

- **Hardware Abstraction via Driver Nodes**: Driver Python modules on Pi isolate hardware details (I2C registers for ESP32s, USB serial for Waveshare adapters, HAT APIs for LEDs/PWM) from application logic. _Rationale: Modules replaceable without changing high-level code, standard robotics pattern._ **Phase 2 caveat (2026-05-15):** the expression engine consumes these drivers **in-process** via Protocol-shaped adapters, not over intermediate ROS 2 topics. The per-module semantic topics (`Expression`/`EarsPose`/`Gesture`/`HeartRate`) were retired; any low-level ROS topic surface that remains is for inspection/debugging only.

- **Expression Engine Pattern (Subscribe-only renderer of canonical events)** *(Phase 2, replaces "Hybrid AI Processing")*: AI/STT/reasoning/personality run in the sibling `olaf_companion` pipeline, which publishes 4 canonical ROS 2 topics. This repo runs a single long-lived **expression engine** that subscribes only, validates the schema-3 envelope fail-fast, and renders each canonical name to pose/LED/eye/heart via a body-side `expression_map.yaml`. It never publishes back. _Rationale: single-writer-per-topic prevents drift; rendering decisions are data, owned consumer-side; the wire is the contract. See `docs/sprint-change-proposal-2026-05-15.md`._

- **Event-Driven Communication (ROS2 Pub/Sub)**: Asynchronous message passing between ROS2 nodes enables loose coupling. ESP32 modules use interrupt-driven I2C to minimize latency. _Rationale: Responsive (<500ms expression sync), power-efficient, decouples producers/consumers._

- **Repository Pattern (Conversation & Config Storage)**: SQLite abstraction layer for data persistence, encapsulates queries. _Rationale: Testable without database, future migration to cloud storage possible._

- **Reduced Firmware Footprint (2 ESP32 Modules Only)**: Only Head (eyes) and Base (balancing) require dedicated ESP32 firmware. All other hardware managed by Pi ROS2 nodes. _Rationale: Fewer firmware projects to maintain, faster iteration, reduced OTA complexity._

- **Autonomous Real-Time Control Pattern (Base Self-Balancing)**: Critical timing loops (200Hz PID balancing) run entirely on Base ESP32 with hardware timers, Pi sends only abstract navigation commands. _Rationale: Linux cannot guarantee real-time deadlines, ESP32 FreeRTOS provides hard real-time guarantees essential for stability._

- **Dual Battery Isolation (Power + Logic)**: 36V hoverboard battery powers high-current systems (motors, servos, ESP32s) via buck converters, while dedicated 2000mAh 7.4V battery powers logic systems (Pi, HATs, display, LEDs) via Fusion HAT. _Rationale: Isolates sensitive electronics from motor noise, enables independent charging, prevents brownouts during motor startup._

---

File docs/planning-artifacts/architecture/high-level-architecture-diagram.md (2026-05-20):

# High Level Architecture Diagram

> **Phase 2 redirect (2026-05-15).** The "Intelligence Layer" and the personality/AI bullets in the Pi block below now live in the sibling `olaf_companion` pipeline, which publishes 4 canonical ROS 2 topics (`mood`, `activity`, `speech_emotion`, `vocalization`, schema_version=3). This repo's Pi role is the **expression engine**: subscribe to those topics and render on the body. See `docs/sprint-change-proposal-2026-05-15.md`.

```
┌─────────────────────────────────────────────────────────────────┐
│      olaf_companion VOICE-AGENT PIPELINE (separate project)     │
│  STT · agent reasoning · personality · mood/activity/emotion    │
│  Publishes 4 canonical ROS 2 topics (std_msgs/String, schema 3):│
│   /olaf/mood  /olaf/activity  /olaf/speech_emotion              │
│                                /olaf/vocalization               │
└──────────────────────┬──────────────────────────────────────────┘
                       │
                       │ ROS 2 / DDS (subscribe-only; same or LAN host)
                       │
┌──────────────────────▼──────────────────────────────────────────┐
│       ORCHESTRATION LAYER (Pi 5 + Fusion HAT+ + AI HAT)         │
│                   Powered by 2000mAh 7.4V Battery               │
│  ┌────────────────────────────────────────────────────────────┐ │
│  │ RASPBERRY PI 5 16GB                                        │ │
│  │  • ROS2 Jazzy (driver packages)                            │ │
│  │  • Expression Engine (subscribes to olaf_companion)        │ │
│  │  • Renders pose/LED/eye/heart from expression_map.yaml     │ │
│  │  • I2C Master (GPIO2/3)     • OTA Server                   │ │
│  └────────────────────────────────────────────────────────────┘ │
│  ┌─────────────────┐ ┌─────────────────┐ ┌──────────────────┐   │
│  │ FUSION HAT+     │ │ AI HAT (Hailo)  │ │ 4" HEART DISPLAY │   │
│  │ • WS2812 port   │ │ • 26 TOPS       │ │ • Animated heart │   │
│  │ • PWM (P0-P3)   │ │ • Whisper STT   │ │ • Status info    │   │
│  │ • I2C bridge    │ │ • Vision models │ │ • SPI from Pi    │   │
│  │ • I2S speaker   │ └─────────────────┘ └──────────────────┘   │
│  └────────┬────────┘                                            │
│           │                                                      │
└───┬───────┼───────┬─────────────────┬───────────────────────────┘
    │       │       │                 │
    │I2C    │PWM    │USB ×2           │WS2812
    │       │       │                 │Data
┌───▼───┐ ┌─▼─────┐ │           ┌─────▼─────────────────────────┐
│ HEAD  │ │KICK-  │ │           │     WS2812 INDICATOR STRIP    │
│ ESP32 │ │STAND  │ │           │     (24 LEDs, 3×8 daisy)      │
│ 0x10  │ │2×Servo│ │           │  ┌────────┬────────┬────────┐ │
└───┬───┘ │4.8-7.4V│ │          │  │Strip 1 │Strip 2 │Strip 3 │ │
    │     │(at base)│ │          │  │Interact│Status  │PID     │ │
┌───▼───┐ └────────┘ │           │  │8 LEDs  │8 LEDs  │8 LEDs  │ │
│2×OLED │             │           └──┴────────┴────────┴────────┘ │
│Eyes   │             │
│SPI    │       ┌─────┴─────────────────────────────┐
└───────┘       │                                   │
                ▼                                   ▼
    ┌───────────────────────┐         ┌───────────────────────┐
    │ WAVESHARE BUS SERVO   │         │ WAVESHARE BUS SERVO   │
    │ ADAPTER (A) - NECK    │         │ ADAPTER (A) - EARS    │
    │ USB Serial            │         │ USB Serial            │
    └───────────┬───────────┘         └───────────┬───────────┘
                │                                 │
    ┌───────────▼───────────┐         ┌───────────▼───────────┐
    │ NECK SERVOS           │         │ EAR SERVOS            │
    │ 3× Feetech STS3215    │         │ 4× Feetech SCS0009    │
    │ Pan / Tilt / Roll     │         │ 2-DOF × 2 ears        │
    │ 30 kg·cm torque       │         │ Daisy-chained         │
    └───────────────────────┘         └───────────────────────┘

┌─────────────────────────────────────────────────────────────────┐
│                    I2C BUS (GPIO2 SDA, GPIO3 SCL)               │
└────────────────────────┬────────────────────────────────────────┘
                         │
         ┌───────────────┴───────────────┐
         │                               │
    ┌────▼────┐                     ┌────▼────┐
    │  HEAD   │                     │  BASE   │
    │  ESP32  │                     │  ESP32  │
    │  0x10   │                     │  0x11   │
    └────┬────┘                     └────┬────┘
         │                               │
    ┌────▼────────────┐         ┌────────▼────────────────────┐
    │ 2× OLED EYES    │         │ MOTOR & BALANCE SYSTEM      │
    │ 128×64, SPI     │         │ ┌─────────┐ ┌─────────────┐ │
    │ 30-60 FPS       │         │ │ BNO085 │ │ ODrive v3.6 │ │
    │ GC9A01 driver   │         │ │ AHRS    │ │ UART        │ │
    │ Eye animations  │         │ │ 200Hz   │ │ 2× BLDC     │ │
    └─────────────────┘         │ └─────────┘ └─────────────┘ │
                                └─────────────────────────────┘
```

## Power Distribution

```
┌─────────────────────────────────────────────────────────────────┐
│              36V HOVERBOARD BATTERY (Charging Port A)           │
└────────┬────────────────────┬────────────────────┬──────────────┘
         │                    │                    │
         │ 36V Direct         │ 36V→12V Buck       │ 36V→5V Buck
         │                    │                    │
    ┌────▼────┐         ┌─────▼─────┐        ┌─────▼─────────────┐
    │ ODrive  │         │ SERVOS    │        │ ESP32s + OLED     │
    │ + BLDC  │         │ Neck ×3   │        │ • Head ESP32      │
    │ Motors  │         │ Ears ×4   │        │ • Base ESP32      │
    │         │         │ (12V in)  │        │ • 2× OLED eyes    │
    └─────────┘         └───────────┘        └───────────────────┘

┌─────────────────────────────────────────────────────────────────┐
│          2000mAh 7.4V BATTERY (Fusion HAT, Charging Port B)     │
└─────────────────────────────┬───────────────────────────────────┘
                              │
                    ┌─────────▼─────────┐
                    │ LOGIC SYSTEM      │
                    │ • Raspberry Pi 5  │
                    │ • Fusion HAT+     │
                    │ • AI HAT (Hailo)  │
                    │ • 4" Heart Display│
                    │ • WS2812 (24 LED) │
                    │ • Kickstand ×2    │
                    └───────────────────┘
```

## Communication Protocols

```
━━━━━━━━ I2C: Pi ↔ 2× ESP32 (Head 0x10, Base 0x11) - 5-20ms latency
─ ─ ─ ─  USB Serial: Pi ↔ 2× Waveshare Adapters (Neck, Ears servos)
- - - -  WiFi: Pi → Cloud AI APIs only (Claude/GPT-4)
━ ━ ━ ━  SPI: Head ESP32 → OLED displays (high-speed graphics)
━·━·━·━  UART: Base ESP32 → ODrive (motor commands, odometry)
────────  WS2812: Pi Fusion HAT → 24 LED strip (single data line)
─·─·─·─  PWM: Pi Fusion HAT → Kickstand servos (long wire to base)
```

## ROS2 Node Topology

```
┌─────────────────────────────────────────────────────────────────┐
│                    ROS2 HUMBLE (on Pi 5)                        │
│                                                                 │
│  ┌──────────────┐  ┌──────────────┐  ┌───────────────────────┐  │
│  │ olaf_head    │  │ olaf_base    │  │ olaf_indicator        │  │
│  │ I2C → 0x10   │  │ I2C → 0x11   │  │ HAT WS2812            │  │
│  │              │  │              │  │                       │  │
│  │ /head/expr   │  │ /cmd_vel     │  │ /indicator/interact   │  │
│  │ /head/blink  │  │ /odom        │  │ /indicator/status     │  │
│  │ /head/look   │  │ /imu         │  │ /indicator/pid        │  │
│  └──────────────┘  └──────────────┘  └───────────────────────┘  │
│                                                                 │
│  ┌──────────────┐  ┌──────────────┐  ┌───────────────────────┐  │
│  │ neck_driver  │  │ head_ears_drv│  │ expression_engine     │  │
│  │ USB Serial   │  │ USB Serial   │  │ subscribes to         │  │
│  │ (in-process) │  │ (in-process) │  │ olaf_companion's wire │  │
│  │              │  │              │  │ /olaf/mood /activity  │  │
│  │              │  │              │  │ /speech_emotion /voc. │  │
│  └──────────────┘  └──────────────┘  └───────────────────────┘  │
│                                                                 │
└─────────────────────────────────────────────────────────────────┘
```

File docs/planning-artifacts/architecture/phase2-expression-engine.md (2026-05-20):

# Phase 2 Architecture — Expression Engine

**Status:** Draft for review · **Author:** Winston (Architect) · **Date:** 2026-05-15
**Implements:** `docs/prd/phase2-prd.md` · **Anchored on:** `docs/sprint-change-proposal-2026-05-15.md`, companion `olaf-embodiment-brief.md` (Appendix A/B)

> This is the *how* for Phase 2. It is the artifact Dev needs before Epic 6. It is deliberately concrete at the Protocol and schema level (those are the contracts that freeze in Story 6.4). Decisions already locked in the SCP/PRD are not re-opened here.

---

## 1. Scope & Posture

The `expression_engine` ROS 2 package is a **single long-running, subscribe-only consumer** of the `olaf_companion` pipeline's four canonical topics. It owns every "what does that look like?" decision via `expression_map.yaml`; it owns no "what does that mean?" decision. It never publishes to the four topics. It imports Phase 1 driver Python classes **in-process** behind Protocol-shaped adapters — no intermediate ROS topics for low-level control.

```
┌─ olaf_companion (separate repo) ─────────────────────────────┐
│  STT · reasoning · personality · mood/activity/emotion FSM   │
│  Publishes std_msgs/String (EventEnvelope JSON, schema 3):   │
│   /olaf/mood  /olaf/activity  /olaf/speech_emotion           │
│                                /olaf/vocalization            │
└───────────────────────────────┬──────────────────────────────┘
                                 │ ROS 2 / DDS (RELIABLE, subscribe-only)
┌────────────────────────────────▼─────────────────────────────┐
│ expression_engine (this repo, one ROS 2 node)                │
│                                                              │
│  subscribers ─► schema(validate, fail-fast) ─► state model   │
│       map_loader (expression_map.yaml, pinned-vocab strict)  │
│                          │                                   │
│                  render_loop (fixed tick)  ◄── idle FSM      │
│                          │                                   │
│        ┌─────────────────┼───────────────┬──────────┐        │
│     neck_adapter     ears_adapter     eye_adapter  led/heart  │
│   (continuous)       (continuous)    (delegating)  (engine-   │
│        │                 │                │         owned)    │
└────────┼─────────────────┼────────────────┼──────────────────┘
   NeckServoDriver   EarsServoDriver   HeadI2CClient   WS2812 / 4" display
   (Phase 1, in-process)                (smart peripheral: ESP32 owns eye anim)
```

---

## 2. The Defining Distinction — Continuous vs Delegating Adapters

Inspection of the Phase 1 drivers (grounding, not assumption) yields two adapter *kinds*. This is the most important architectural decision in Phase 2; everything downstream follows from it.

| Kind | Drivers | Engine responsibility | Tick? |
|---|---|---|---|
| **Continuous** | `neck_adapter` → `NeckServoDriver`, `ears_adapter` → `EarsServoDriver` | Engine computes target joint angles from the map, **interpolates per render tick**, and issues `move_*` calls. Easing, anticipatory window, gesture attack all live in the engine. | Yes — driven by `render_loop` |
| **Delegating** | `eye_adapter` → `HeadI2CClient` | Engine forwards a **semantic** `set_expression(name, intensity)` / `trigger_blink()` / `set_look_direction(x,y)` to the Head ESP32, which owns 60 FPS eye animation (Phase 1 Smart Peripheral Pattern). Engine does **not** interpolate eyes per tick. | No — fire-on-change |
| **Engine-owned** | `led_adapter` (WS2812), `heart_adapter` (4" display) | No Phase 1 driver exists; the engine renders these directly. Continuous for LED breathe; fire-on-change otherwise. | LED: yes; heart: low-rate |

**Consequence:** the render loop interpolates *neck + ears* every tick; it pushes *eye* state only on transitions (and lets the ESP32 ease); it ticks *LED* for breathe and pushes *heart* at a low rate. The 30–80ms anticipatory window (NFR2) is therefore enforced for neck/ears in the loop, and for eyes by *sending the semantic event early* (the ESP32's own ramp covers the rest).

---

## 3. Component Breakdown

`ros2/src/expression_engine/expression_engine/`

| Module | Responsibility |
|---|---|
| `node.py` | ROS 2 node lifecycle; owns the executor; wires subscribers → state → render thread; startup-validation sequence (§9). |
| `schema.py` | `EventEnvelope` + 4 payload pydantic models (schema-3). `assert_schema_version` → raise/journald/exit on mismatch (FR4). |
| `subscribers.py` | Four `std_msgs/String` subscriptions; deserialize JSON → `schema.py` models; hand validated events to the state model. |
| `state.py` | Holds current **mood** (base), **activity** (base posture), last **speech_emotion** (overlay, with TTL), pending **vocalization** queue. The single source of "what should the body be expressing now". |
| `map_loader.py` | Load + validate `expression_map.yaml` against the pinned canonical set (FR6, NFR5); enforce `visible_only` on `nod`/`shake` (FR7). |
| `render_loop.py` | Fixed-tick loop: compose target pose from state + map (§5), interpolate, drive continuous adapters; push delegating/engine-owned adapters on change. |
| `idle.py` | Idle FSM (§7). Decides when state→render falls back to ambient. |
| `adapters/base.py` | The Protocols (§4). |
| `adapters/{neck,ears,eye,led,heart}_adapter.py` | Concrete adapters wrapping Phase 1 classes / hardware. |
| `config/expression_map.yaml`, `config/expression_engine.toml` | Vocabulary→render + service config. |

**Concurrency model:** one `rclpy` executor thread handles subscriptions and writes to `state` (lock-guarded, last-write-wins per topic — the companion already dedups `speech_emotion`). A separate **render thread** runs the fixed-tick loop reading `state`. State is a small mutex-protected snapshot; the render loop copies it per tick and never blocks on DDS. This keeps the tick jitter-free regardless of event cadence.

---

## 4. Adapter Protocols (the contract that freezes in Story 6.4)

> 🔒 **FROZEN — 2026-05-17, Story 6.4, proven on real hardware @ commit `0f43dfa`.** The three Protocols (`ContinuousAdapter`, `DelegatingAdapter`, `SurfaceAdapter`) + `SurfaceFrame` in `ros2/src/expression_engine/expression_engine/adapters/base.py` are LOCKED. Concrete `neck`/`ears`/`eye` adapters were instantiated and the reference `happy` expression rendered end-to-end on neck + ears + eyes (mock publisher → engine → real drivers). **Epic 7 authors expression *content* only — no Protocol signature changes.** Any post-freeze change is a documented amendment with re-proof on hardware.

`adapters/base.py` — structural `typing.Protocol`s. Concrete adapters wrap the real Phase 1 driver classes; signatures below are grounded in the actual driver APIs.

```python
from dataclasses import dataclass
from typing import Protocol, runtime_checkable

@runtime_checkable
class ContinuousAdapter(Protocol):
    """Joint-space adapter the render loop ticks. Engine owns interpolation."""
    def connect(self) -> None: ...           # fatal on failure (NFR7)
    def close(self) -> None: ...
    def apply(self, targets: dict[str, float], speed_pct: float = 0.0) -> None:
        """Issue absolute joint angles (deg). Called every tick with the
        loop's interpolated values — the adapter does NOT ease."""
    def neutral(self) -> dict[str, float]:
        """The joint-space 'centered' pose, for idle/return-to-base."""

@runtime_checkable
class DelegatingAdapter(Protocol):
    """Semantic adapter for a smart peripheral that owns its own animation."""
    def connect(self) -> None: ...
    def close(self) -> None: ...
    def set_expression(self, canonical_name: str, intensity: int) -> None: ...
    def blink(self) -> None: ...
    def look(self, x: int, y: int) -> None: ...

@dataclass(frozen=True)
class SurfaceFrame:                # the render() payload — frozen with the Protocols
    led_color: str = "#404040"
    led_intensity: float = 0.2
    led_pattern: str = "solid"
    heart_bpm: int = 60
    heart_intensity: int = 2
    heart_color: str = "#802020"

@runtime_checkable
class SurfaceAdapter(Protocol):
    """Engine-owned surface (LED strip, heart display)."""
    def connect(self) -> None: ...
    def close(self) -> None: ...
    def render(self, frame: SurfaceFrame) -> None: ...   # called per tick (LED) / low-rate (heart)
```

`SurfaceFrame` (defined for the freeze — Story 6.3 shipped it in `adapters/base.py`; no real surface adapter consumes it until §6.6/8.1). The three Protocols (`ContinuousAdapter`, `DelegatingAdapter`, `SurfaceAdapter`) are **unchanged** from the original §4 and freeze AS-IS in Story 6.4.

**Concrete mappings (grounded in Phase 1 driver signatures):**

| Adapter | Wraps | Maps Protocol call → driver call |
|---|---|---|
| `neck_adapter` | `NeckServoDriver` | `apply({"pan":p,"tilt":t,"roll":r})` → `move_pose(pan=p, tilt=t, roll=r, speed=…)`; `neutral()` → centered triple; `connect/close` → driver ctor / `close()` |
| `ears_adapter` | `EarsServoDriver` | `apply({"left_pan":…,"left_tilt":…,"right_pan":…,"right_tilt":…})` → `move_left_pan/left_tilt/right_pan/right_tilt(deg, speed_pct)`; `neutral()` → `center_all()` targets |
| `eye_adapter` | `HeadI2CClient` | `set_expression(name,intensity)` → `set_expression(name,intensity)`; `blink()` → `trigger_blink()`; `look(x,y)` → `set_look_direction(x,y)`; `connect()` → `open()` |
| `led_adapter` | *(engine-owned WS2812)* | `render(frame)` → drive 24 LEDs from `frame.led_color/intensity/pattern` |
| `heart_adapter` | *(engine-owned 4" display)* | `render(frame)` → draw heart from `frame.heart_bpm/intensity/color` |

`NFR6` (one-adapter hardware swap) is satisfied by construction: anything new implements one Protocol; nothing else changes.

---

## 5. `expression_map.yaml` Schema & the Layering Model

### 5.1 Layering / composition

The body output each tick is composed in a fixed order (companion brief §"What Makes This Different" #4/#5):

```
ACTIVITY  → base posture (held)            e.g. listening = upright
   └─ MOOD → subtle modifier on the base   small lean/LED bias only (low impact, PRD 7.4)
        └─ SPEECH_EMOTION → overlay        per-utterance; decays to base after 3s silence
             └─ VOCALIZATION → punctuation transient gesture added on top, then released
```

Disambiguation is **by topic, not by name** — `mood.happy` and `speech_emotion.happy` are different keys with different renders (brief #4). The render loop resolves: `target = compose(activity_base, mood_bias, speech_overlay, active_vocalization)`.
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

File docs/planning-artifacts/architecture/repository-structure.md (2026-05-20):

# Repository Structure

**Structure:** Monorepo

**Monorepo Tool:** Git (no specialized monorepo tool needed for this scale)

**Organization Principle:** Module-first architecture with hybrid control topology. ESP32 modules (Head, Base) contain firmware for real-time tasks, while Pi-controlled modules (Neck, Ears, Indicator) are driver-only packages managed directly via Fusion HAT interfaces.

> **Phase 2 note (2026-05-15).** The `ros2/src` tree below is partly aspirational and predates the Phase 2 re-scope. Actual driver packages are `head_ears_driver`, `neck_driver`, `base_driver`, `torso_driver` (not the idealized `olaf_head`/`olaf_base`/… names shown). `olaf_personality` was removed and replaced by `expression_engine` (subscribe-only renderer of `olaf_companion`'s 4-topic schema-3 contract). Authoritative Phase 2 structure: `docs/sprint-change-proposal-2026-05-15.md` §5.
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

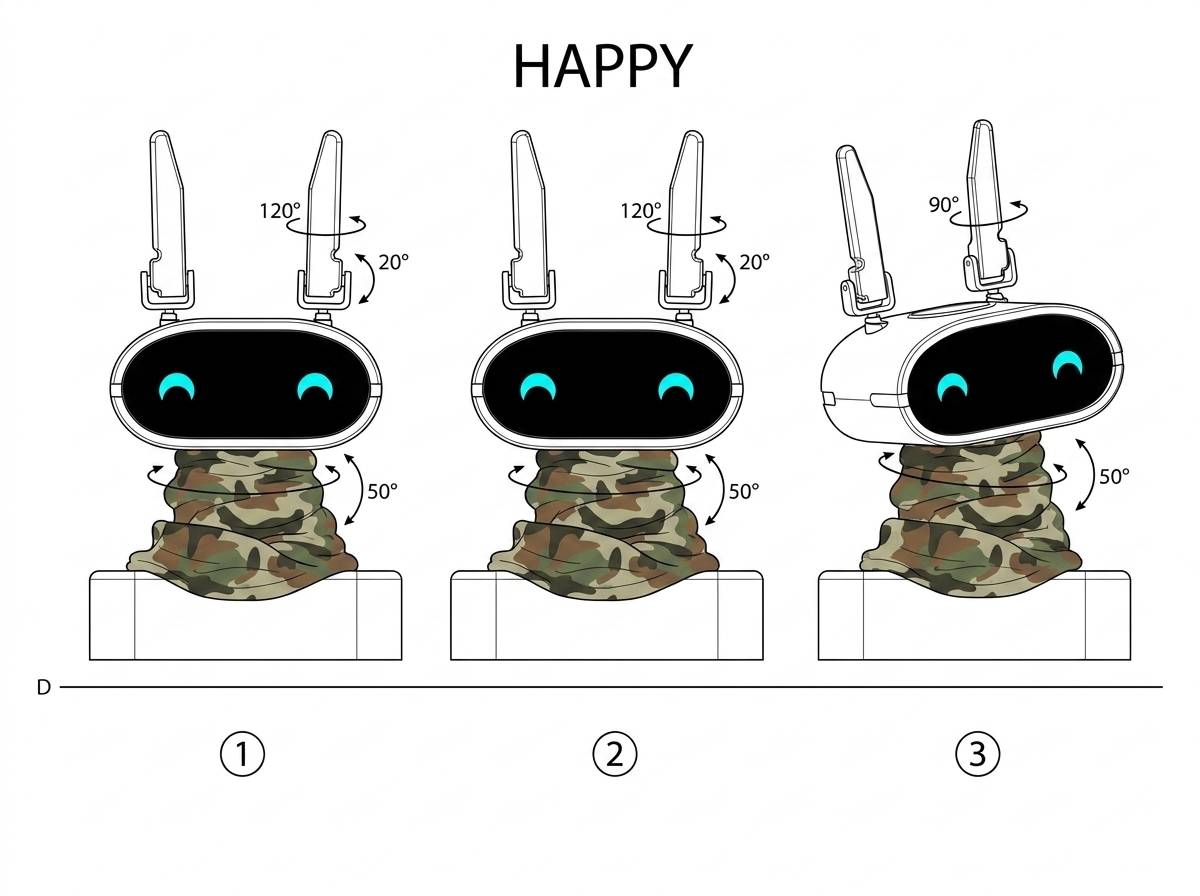
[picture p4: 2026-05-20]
docs/planning-artifacts/ux-reference-sheets/expression-happy-refsheet-v8.png

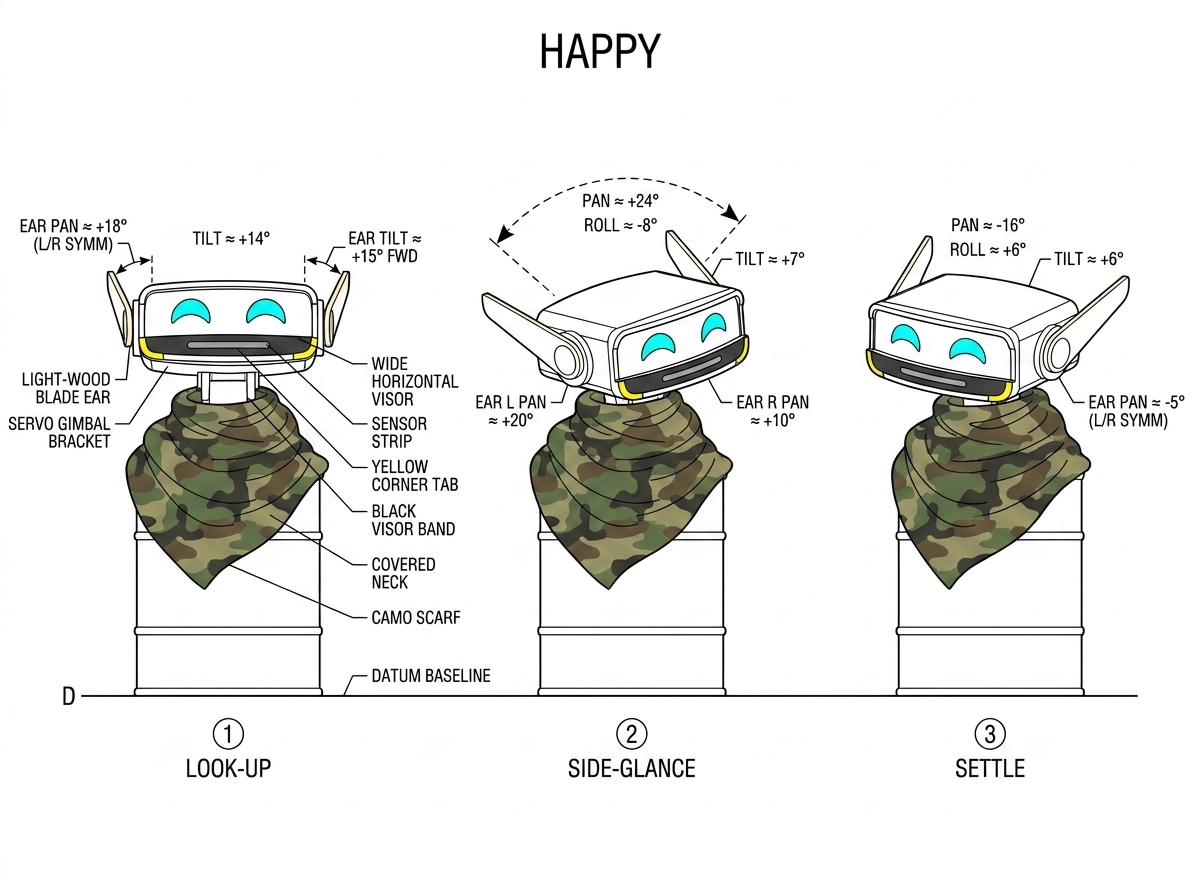
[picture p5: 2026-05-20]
docs/planning-artifacts/ux-reference-sheets/expression-happy-refsheet-v9.png

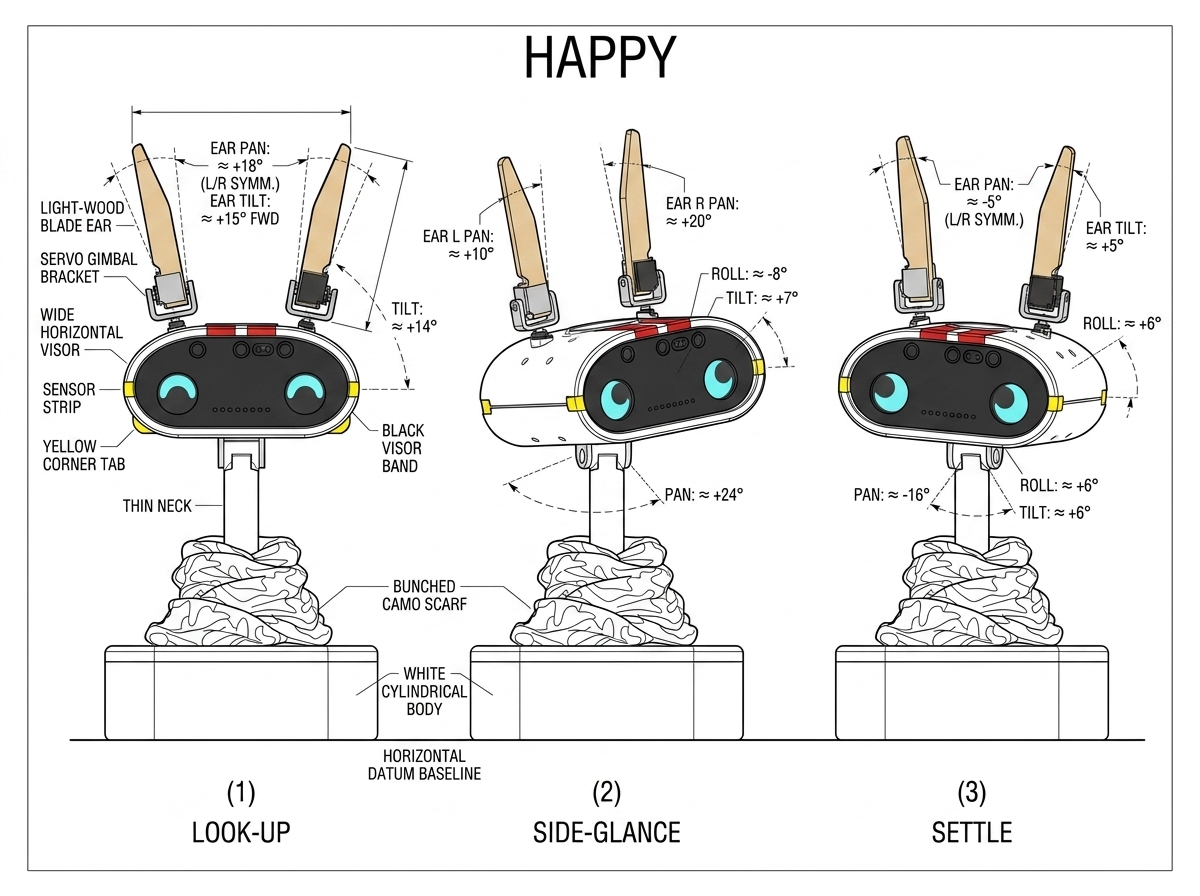
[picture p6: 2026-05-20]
docs/planning-artifacts/ux-reference-sheets/expression-happy-refsheet-v7.png

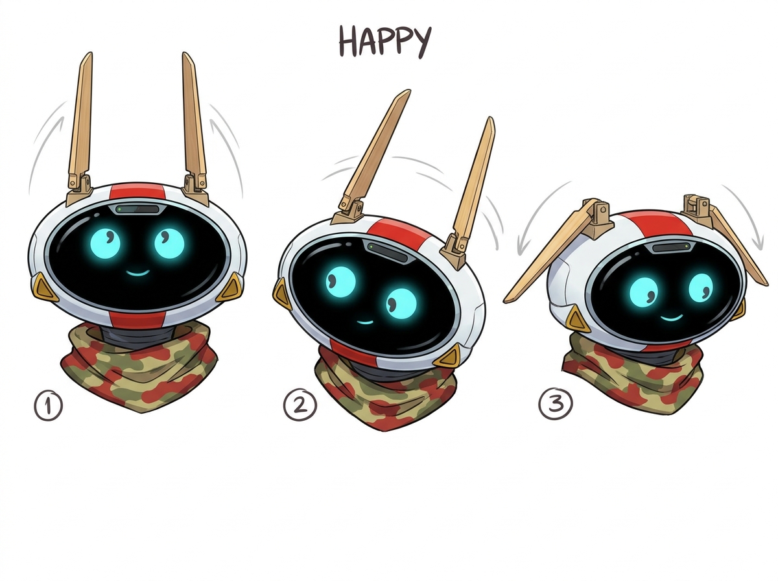
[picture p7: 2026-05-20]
docs/planning-artifacts/ux-reference-sheets/expression-happy-refsheet-v3.png

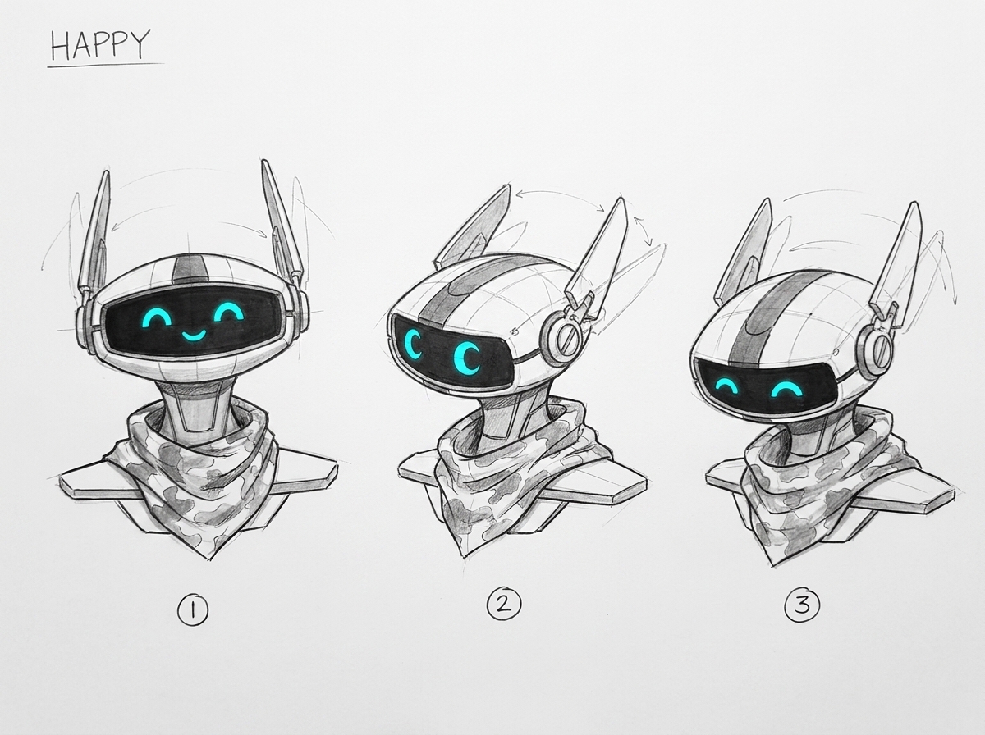
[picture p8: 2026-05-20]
docs/planning-artifacts/ux-reference-sheets/expression-happy-refsheet-v5.png

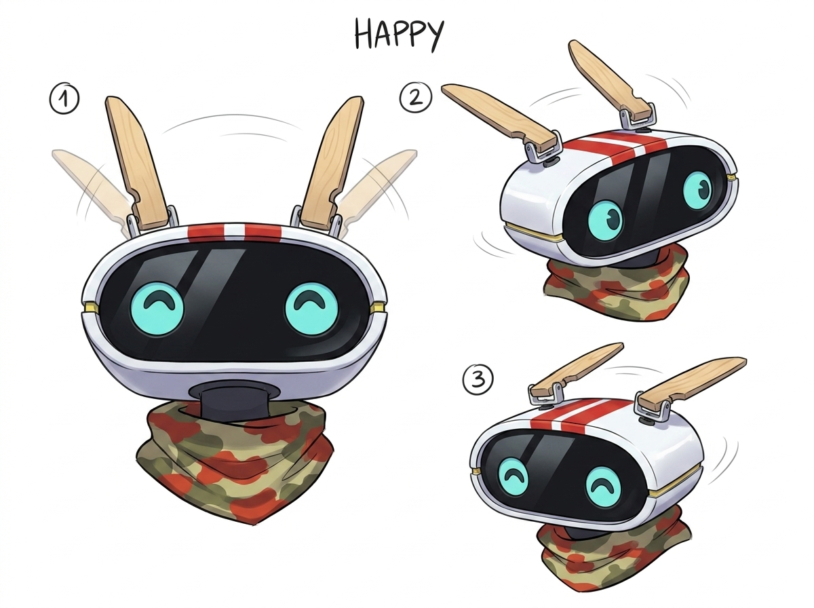
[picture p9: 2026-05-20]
docs/planning-artifacts/ux-reference-sheets/expression-happy-refsheet-v4.png

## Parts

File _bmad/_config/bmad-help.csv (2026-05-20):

module | skill | display-name | menu-code | description | action | args | phase | after | before | required | output-location | outputs
BMad Method | _meta |  |  |  |  |  |  |  |  | false | https://docs.bmad-method.org/llms.txt
BMad Method | bmad-brainstorming | Brainstorm Project | BP | Expert guided facilitation through a single or multiple techniques. |  |  | 1-analysis |  |  | false | planning_artifacts | brainstorming session
BMad Method | bmad-market-research | Market Research | MR | Market analysis competitive landscape customer needs and trends. |  |  | 1-analysis |  |  | false | planning_artifacts|project-knowledge | research documents
BMad Method | bmad-domain-research | Domain Research | DR | Industry domain deep dive subject matter expertise and terminology. |  |  | 1-analysis |  |  | false | planning_artifacts|project_knowledge | research documents
BMad Method | bmad-technical-research | Technical Research | TR | Technical feasibility architecture options and implementation approaches. |  |  | 1-analysis |  |  | false | planning_artifacts|project_knowledge | research documents
BMad Method | bmad-product-brief | Create Brief | CB | An expert guided experience to nail down your product idea in a brief. a gentler approach than PRFAQ when you are already sure of your concept and nothing will sway you. |  | -A | 1-analysis |  |  | false | planning_artifacts | product brief
BMad Method | bmad-prfaq | PRFAQ Challenge | WB | Working Backwards guided experience to forge and stress-test your product concept to ensure you have a great product that users will love and need through the PRFAQ gauntlet to determine feasibility and alignment with user needs. alternative to product brief. |  | -H | 1-analysis |  |  | false | planning_artifacts | prfaq document
BMad Method | bmad-create-prd | Create PRD | CP | Expert led facilitation to produce your Product Requirements Document. |  |  | 2-planning |  |  | true | planning_artifacts | prd
BMad Method | bmad-validate-prd | Validate PRD | VP |  |  | [path] | 2-planning | bmad-create-prd |  | false | planning_artifacts | prd validation report
BMad Method | bmad-edit-prd | Edit PRD | EP |  |  | [path] | 2-planning | bmad-validate-prd |  | false | planning_artifacts | updated prd
BMad Method | bmad-create-ux-design | Create UX | CU | Guidance through realizing the plan for your UX, strongly recommended if a UI is a primary piece of the proposed project. |  |  | 2-planning | bmad-create-prd |  | false | planning_artifacts | ux design
BMad Method | bmad-create-architecture | Create Architecture | CA | Guided workflow to document technical decisions. |  |  | 3-solutioning |  |  | true | planning_artifacts | architecture
BMad Method | bmad-create-epics-and-stories | Create Epics and Stories | CE |  |  |  | 3-solutioning | bmad-create-architecture |  | true | planning_artifacts | epics and stories
BMad Method | bmad-check-implementation-readiness | Check Implementation Readiness | IR | Ensure PRD UX Architecture and Epics Stories are aligned. |  |  | 3-solutioning | bmad-create-epics-and-stories |  | true | planning_artifacts | readiness report
BMad Method | bmad-sprint-planning | Sprint Planning | SP | Kicks off implementation by producing a plan the implementation agents will follow in sequence for every story. |  |  | 4-implementation |  |  | true | implementation_artifacts | sprint status
BMad Method | bmad-sprint-status | Sprint Status | SS | Anytime: Summarize sprint status and route to next workflow. |  |  | 4-implementation | bmad-sprint-planning |  | false
BMad Method | bmad-create-story | Create Story | CS | Story cycle start: Prepare first found story in the sprint plan that is next or a specific epic/story designation. | create |  | 4-implementation | bmad-sprint-planning | bmad-create-story:validate | true | implementation_artifacts | story
BMad Method | bmad-create-story | Validate Story | VS | Validates story readiness and completeness before development work begins. | validate |  | 4-implementation | bmad-create-story:create | bmad-dev-story | false | implementation_artifacts | story validation report
BMad Method | bmad-dev-story | Dev Story | DS | Story cycle: Execute story implementation tasks and tests then CR then back to DS if fixes needed. |  |  | 4-implementation | bmad-create-story:validate |  | true
BMad Method | bmad-code-review | Code Review | CR | Story cycle: If issues back to DS if approved then next CS or ER if epic complete. |  |  | 4-implementation | bmad-dev-story |  | false
BMad Method | bmad-checkpoint-preview | Checkpoint | CK | Guided walkthrough of a change from purpose and context into details. Use for human review of commits branches or PRs. |  |  | 4-implementation |  |  | false
BMad Method | bmad-qa-generate-e2e-tests | QA Automation Test | QA | Generate automated API and E2E tests for implemented code. NOT for code review or story validation — use CR for that. |  |  | 4-implementation | bmad-dev-story |  | false | implementation_artifacts | test suite
BMad Method | bmad-retrospective | Retrospective | ER | Optional at epic end: Review completed work lessons learned and next epic or if major issues consider CC. |  |  | 4-implementation | bmad-code-review |  | false | implementation_artifacts | retrospective
BMad Method | bmad-document-project | Document Project | DP | Analyze an existing project to produce useful documentation. |  |  | anytime |  |  | false | project-knowledge | *
BMad Method | bmad-generate-project-context | Generate Project Context | GPC | Scan existing codebase to generate a lean LLM-optimized project-context.md. Essential for brownfield projects. |  |  | anytime |  |  | false | output_folder | project context
BMad Method | bmad-quick-dev | Quick Dev | QQ | Unified intent-in code-out workflow: clarify plan implement review and present. |  |  | anytime |  |  | false | implementation_artifacts | spec and project implementation
BMad Method | bmad-correct-course | Correct Course | CC | Navigate significant changes. May recommend start over update PRD redo architecture sprint planning or correct epics and stories. |  |  | anytime |  |  | false | planning_artifacts | change proposal
BMad Method | bmad-agent-tech-writer | Write Document | WD | Describe in detail what you want, and the agent will follow documentation best practices. Multi-turn conversation with subprocess for research/review. | write |  | anytime |  |  | false | project-knowledge | document
BMad Method | bmad-agent-tech-writer | Update Standards | US | Update agent memory documentation-standards.md with your specific preferences if you discover missing document conventions. | update-standards |  | anytime |  |  | false | _bmad/_memory/tech-writer-sidecar | standards
BMad Method | bmad-agent-tech-writer | Mermaid Generate | MG | Create a Mermaid diagram based on user description. Will suggest diagram types if not specified. | mermaid |  | anytime |  |  | false | planning_artifacts | mermaid diagram
BMad Method | bmad-agent-tech-writer | Validate Document | VD | Review the specified document against documentation standards and best practices. Returns specific actionable improvement suggestions organized by priority. | validate | [path] | anytime |  |  | false | planning_artifacts | validation report
BMad Method | bmad-agent-tech-writer | Explain Concept | EC | Create clear technical explanations with examples and diagrams for complex concepts. | explain | [topic] | anytime |  |  | false | project_knowledge | explanation
Core | _meta |  |  |  |  |  |  |  |  | false | https://docs.bmad-method.org/llms.txt
Core | bmad-brainstorming | Brainstorming | BSP | Use early in ideation or when stuck generating ideas. |  |  | anytime |  |  | false | {output_folder}/brainstorming | brainstorming session
Core | bmad-party-mode | Party Mode | PM | Orchestrate multi-agent discussions when you need multiple perspectives or want agents to collaborate. |  |  | anytime |  |  | false
Core | bmad-help | BMad Help | BH |  |  |  | anytime |  |  | false
Core | bmad-index-docs | Index Docs | ID | Use when LLM needs to understand available docs without loading everything. |  |  | anytime |  |  | false
Core | bmad-shard-doc | Shard Document | SD | Use when doc becomes too large (>500 lines) to manage effectively. |  | [path] | anytime |  |  | false
Core | bmad-editorial-review-prose | Editorial Review - Prose | EP | Use after drafting to polish written content. |  | [path] | anytime |  |  | false | report located with target document | three-column markdown table with suggested fixes
Core | bmad-editorial-review-structure | Editorial Review - Structure | ES | Use when doc produced from multiple subprocesses or needs structural improvement. |  | [path] | anytime |  |  | false | report located with target document
Core | bmad-review-adversarial-general | Adversarial Review | AR | Use for quality assurance or before finalizing deliverables. Code Review in other modules runs this automatically, but also useful for document reviews. |  | [path] | anytime |  |  | false
Core | bmad-review-edge-case-hunter | Edge Case Hunter Review | ECH | Use alongside adversarial review for orthogonal coverage — method-driven not attitude-driven. |  | [path] | anytime |  |  | false
Core | bmad-distillator | Distillator | DG | Use when you need token-efficient distillates that preserve all information for downstream LLM consumption. |  | [path] | anytime |  |  | false | adjacent to source document or specified output_path | distillate markdown file(s)
Core | bmad-customize | BMad Customize | BC | Use when you want to change how an agent or workflow behaves — add persistent facts, swap templates, insert activation hooks, or customize menus. Scans what's customizable, picks the right scope (agent vs workflow), writes the override to _bmad/custom/, and verifies the merge. No TOML hand-authoring required. |  |  | anytime |  |  | false | {project-root}/_bmad/custom | TOML override files

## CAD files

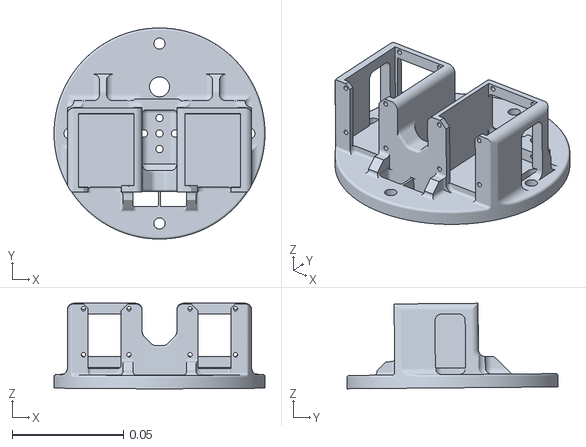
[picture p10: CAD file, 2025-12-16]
modules/neck/hardware/mechanical/neck v2 -parts - base plate.stl
0.095 x 0.095 x 0.0385

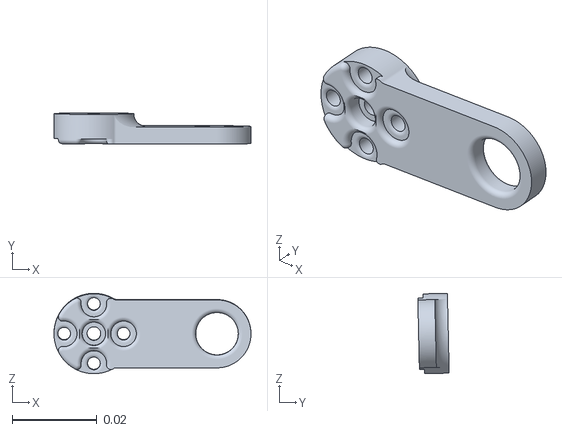
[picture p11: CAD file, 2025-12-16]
modules/neck/hardware/mechanical/neck v2 -parts - neck base servo horn.stl
0.0464 x 0.0074 x 0.0189

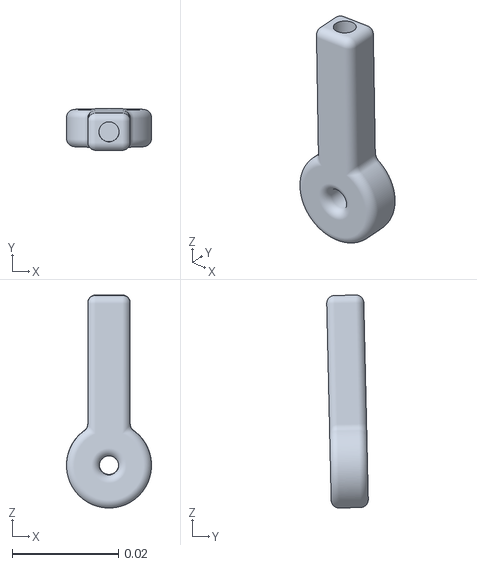
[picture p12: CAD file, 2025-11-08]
modules/neck/hardware/mechanical/neck v2 -parts - neck base connecter.stl
0.016 x 0.00784 x 0.0401

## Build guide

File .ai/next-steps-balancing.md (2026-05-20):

# OLAF Balancing — Next Steps

## Current State (2026-04-11)

### What's Working
- ESP32 firmware: BNO085 IMU (200Hz), ODrive torque/current mode, OLED HUD, OTA flashing
- Web dashboard at http://olaf-base.local: live charts, PID sliders, BALANCE/STOP/TARE/SAVE buttons, REC LOG
- Balance PID: Kp=0.18, Ki=0, Kd=1.0, Target=4.2° — robot balances, resists pushes
- Ziegler-Nichols auto-tuner (relay method) — did NOT produce usable gains, needs replacement
- Velocity outer loop code exists (velocity_controller.cpp) but is DISABLED and untested successfully

### Known Issues
- **Robot drifts** — balances but slowly creeps across the floor
- Velocity loop was attempted but didn't work — likely due to unfiltered 90 CPR Hall encoder noise
- Ki=0.1 caused backward drift/acceleration (integral windup) — keep Ki=0
- Ziegler-Nichols auto-tune produced gains that didn't work on hardware
- ODrive `f <axis>` velocity readback is very noisy at low speeds (~1 count/sec at drift speed)
- After safety trip (45°), motor current display freezes (cosmetic)

### Hardware Facts
- 2x hoverboard motors, 90 CPR Hall encoders (6 states x 15 pole pairs)
- Robot weighs ~10kg, motors rated ~50-60kg each = 10x torque headroom
- BNO085 on-chip AHRS, game rotation vector at 200Hz
- ODrive v3.6, torque/current control mode, ASCII UART protocol
- Wheel diameter 0.17m, circumference ~0.534m → 5.9mm per encoder count

### Research Summary (2026-04-11)
Reviewed multiple self-balancing projects to decide architecture:

| Project | Architecture | Drift Solution | Encoder | Relevant? |
|---|---|---|---|---|
| **mjbots hoverbot** | Velocity PI → Pitch PD → current | Velocity integral | Hall sensors | **Best match** — same motors, same control mode |
| RolfK (Hackster) | Position PID → Balance PID → stepper speed | Position outer loop + hold migration | Stepper pulses (exact) | Twiddle auto-tuner is valuable |
| heethesh Balance-Bot | Position → Velocity → Pitch → motor (4 PIDs) | Full triple cascade | Quadrature encoders | Endgame for SLAM, overkill for now |
| LuSeKa HoverBot | Pitch PD only (no outer loop) | None — drifts, human compensates | None | Not useful |
| SolidGeek ESP32 | Cascade (no encoder feedback) | Velocity estimated from commands | None | Not useful |

**Decision: Follow mjbots hoverbot architecture** — velocity PI → pitch PD cascade. This provides a velocity interface needed for SLAM/Nav2 (`/cmd_vel`), and the velocity integral handles position hold when stationary. Add RolfK's Twiddle auto-tuner for gain optimization.

---

## Phase 1: Fix Velocity Loop + Add Yaw Control (Priority — do first)

The velocity controller code exists and is structurally correct. It failed because of unfiltered encoder noise. The motor controller already has the differential split for yaw (`left = balance + yaw`, `right = balance - yaw`) but only does open-loop proportional turn — needs heading-hold PID like mjbots.

### 1a. Add exponential smoothing to velocity readback

In `velocity_controller.cpp`, filter the raw ODrive velocity before using it:

```cpp
// Add to VelocityController private members:
float filteredVel0_ = 0.0f;
float filteredVel1_ = 0.0f;

// In update(), replace raw reads:
float rawVel0 = odriveUart.readVelocity(0) * kAxis0Direction;
filteredVel0_ = kVelFilterAlpha * filteredVel0_ + (1.0f - kVelFilterAlpha) * rawVel0;

float rawVel1 = odriveUart.readVelocity(1) * kAxis1Direction;
filteredVel1_ = kVelFilterAlpha * filteredVel1_ + (1.0f - kVelFilterAlpha) * rawVel1;

measuredVelocity_ = (filteredVel0_ + filteredVel1_) * 0.5f;
```

Add to `config.h`:
```cpp
constexpr float kVelFilterAlpha = 0.85f;  // Smoothing factor — higher = smoother, slower response
```

Add a slider for alpha (range 0.5-0.99) so it can be tuned on hardware.

### 1b. Add velocity loop enable/disable toggle to web dashboard

- Add a toggle button: "VEL LOOP ON/OFF"
- WebSocket command: `CMD:VELON` / `CMD:VELOFF`
- Calls `velController.setEnabled(true/false)`
- Show enabled state in UI (green/grey indicator)
- When disabled, `getPitchOffset()` returns 0 (existing behavior)

### 1c. Retune velocity gains with filter active

Starting gains (from mjbots scaled to our setup):
- VelKp = 5.0 (keep current)
- VelKi = 2.0 (lower than before — let the filter help)
- VelOutputMaxDeg = 5.0 (keep, increase to 10 if needed)
- VelFilterAlpha = 0.85 (adjust via slider)

Tuning procedure:
1. Get balance PID stable first (current gains should work)
2. Enable velocity loop with VelKi=0 first
3. Increase VelKp until robot resists being pushed to a new position
4. Add VelKi slowly until robot returns to original position after push
5. If oscillation: increase filter alpha (more smoothing) or decrease gains

### 1d. Also read ODrive position (for telemetry / future use)

The `f <axis>` response returns `<pos> <vel>`. Currently we parse only velocity and discard position. Parse both:

```cpp
// In odrive_uart.cpp readVelocity(), also return position:
struct OdriveMotionData {
    float position;   // cumulative turns
    float velocity;   // turns/s
};
OdriveMotionData readMotion(uint8_t axis);
```

Display position on web dashboard. This data feeds into `/odom` for SLAM later (Story 2.8).

### 1e. Add yaw heading-hold PID (mjbots pattern)

Currently `motor_controller.cpp` has a simple proportional turn (`yawCurrent_ = radps * 0.5f`).
Replace with a heading-hold PID that actively maintains heading when yaw command is zero.

**New file: `yaw_controller.h / yaw_controller.cpp`**

Architecture (from mjbots hoverbot):
```
yaw_rate_cmd ──→ integrate ──→ yaw_target
                                    │
                    imu_yaw ──→ heading_error = imu_yaw - yaw_target
                                    │
                              yaw_torque = Kp_yaw * heading_error + Kd_yaw * (gyro_z - cmd_yaw_rate)
```

Implementation:
```cpp
class YawController {
public:
    void begin();
    void reset();                          // Capture current yaw as target
    void update(float dt);                 // Run heading PID
    void setYawRate(float radps);          // From joystick / cmd_vel
    float getYawTorque() const;            // Feed into motor controller

private:
    float yawTarget_;                      // Integrated heading target (degrees)
    float yawRateCmd_;                     // Commanded yaw rate (rad/s)
    float yawTorque_;                      // Output torque (Amps differential)
};
```

Key behaviors:
- On BALANCE start: `yawTarget_ = imu.getYaw()` — capture current heading
- Each cycle: `yawTarget_ += yawRateCmd_ * RAD_TO_DEG * dt` — integrate command
- PID: `yawTorque = Kp_yaw * wrap180(imu_yaw - yawTarget) + Kd_yaw * (gyro_z - yawRateCmd)`
- When yaw_rate = 0: **actively holds heading** — robot won't rotate if bumped sideways
- This is critical for SLAM (consistent orientation during mapping)

Config defaults (from mjbots, scaled ~40% of pitch gains):
```cpp
constexpr float kYawKp = 0.01f;           // Nm per degree heading error — start conservative
constexpr float kYawKd = 0.001f;          // Nm per deg/s rate error
constexpr float kYawOutputMaxAmps = 2.0f; // Don't let yaw destabilize balance
```

Add Yaw Kp/Kd sliders to web dashboard for tuning.

Integration in `motor_controller.cpp` — replace `setTurnRate()`:
```cpp
// In applyCurrents(), yawCurrent_ now comes from yawController.getYawTorque()
// instead of the simple proportional
float left = balanceCurrent_ + yawController.getYawTorque();
float right = balanceCurrent_ - yawController.getYawTorque();
```

### 1f. BNO085 yaw data

Verify `imu.cpp` exposes yaw angle and gyro Z:
- `imu.getYaw()` — heading in degrees from game rotation vector
- `imu.getGyroZ()` — yaw rate in rad/s (already used in telemetry)
- BNO085 game rotation vector does NOT have magnetometer correction → yaw drifts over time
- For short-term heading hold this is fine. For SLAM, wheel odometry provides yaw correction.
- If `getYaw()` doesn't exist yet, add it alongside existing `getPitch()`/`getRoll()`

---

## Phase 2: Replace Auto-Tuner with Twiddle

The current Ziegler-Nichols relay method didn't produce usable gains. Replace with RolfK's Twiddle algorithm which optimizes gains online.

### 2a. Implement Twiddle optimizer

Algorithm:
```
params = [Kp, Kd, Target, VelKp, VelKi, FilterAlpha]
dp     = [0.02, 0.1, 0.5, 1.0, 1.0, 0.05]  // initial step sizes

while sum(dp) > 0.03:
    for i in range(len(params)):
        params[i] += dp[i]
        run for N seconds, measure avg |pitch_error|
        if better:
            dp[i] *= 1.1  // grow step
            best_error = error
        else:
            params[i] -= 2 * dp[i]  // try other direction
            run for N seconds
            if better:
                dp[i] *= 1.1
                best_error = error
            else:
                params[i] += dp[i]  // restore
                dp[i] *= 0.9  // shrink step
```

### 2b. Integration with web dashboard

- Replace AUTO-TUNE button behavior (or add second button: "TWIDDLE")
- Show live: which parameter is being tweaked, current best error, convergence %
- Robot must be balancing — Twiddle runs during live balancing
- Safety: if robot falls, restore last-known-good params, restart
- Save best params to Preferences when converged

### 2c. Twiddle settings

- Run duration per trial: 4-6 seconds (enough for velocity loop to respond)
- Error metric: average |pitch_error| + weight * |velocity| (penalize both tilt error and drift)
- Convergence threshold: sum(dp) < 0.03
- Safety: abort if pitch > 30° during any trial

---

## Phase 3: Web Joystick + AP Mode (drive it from your phone)

Once velocity loop and yaw heading-hold are working, add phone control.

### 3a. Virtual joystick on web dashboard

Add a touch joystick to the existing dashboard at `http://olaf-base.local`:

- Use **nipplejs** library (lightweight, touch-friendly, MIT license) — or a simple CSS touch-drag div
- Joystick area below the PID sliders section
- Forward/back axis → `setDesiredVelocity()` (range ±1 m/s via `kMaxLinearVelocityMps`)
- Left/right axis → `setYawRate()` (range ±2 rad/s via `kMaxTurnRateRadps`)
- Dead zone in center (~10% of travel)
- Send as WebSocket messages: `JOY:<vel>,<yaw>` at 20Hz while active
- On release: send `JOY:0,0` (stop)

ESP32 side:
```cpp
// In onWsEvent(), parse joystick:
if (strncmp(msg, "JOY:", 4) == 0) {
    float vel, yaw;
    sscanf(msg + 4, "%f,%f", &vel, &yaw);
    velController.setDesiredVelocity(vel);
    yawController.setYawRate(yaw);
}
```

### 3b. AP mode (WiFi hotspot for outdoor use)

For outdoor testing where there's no WiFi network:

- `WiFi.softAP("OLAF-Base", "olaf1234")` → IP: 192.168.4.1
- mDNS still works: `olaf-base.local`
- Auto-detect: try station mode for 10 seconds, fallback to AP if no connection
- OTA still works over AP
- Add a config flag or button to switch modes

### 3c. Dashboard layout for phone

Reorganize the web dashboard for portrait phone use:
- Top: pitch/PID readouts (compact)
- Middle: joystick (large touch target, ~40% of screen)
- Bottom: BALANCE/STOP buttons (large, always visible)
- PID sliders on a separate tab/collapsible section (not needed during driving)

---

## Phase 4: Position Hold Enhancement (if needed after Phase 1-3)

If the velocity integral alone isn't enough for station keeping, add a soft position P-loop (from RolfK):

```
position_error = hold_position - current_position
desired_velocity = Kp_pos * position_error  // very soft: Kp_pos ~ 0.1
→ feeds into velocity PI as setDesiredVelocity()
```

With hold-position migration after disturbances:
```
hold_position = 0.9 * hold_position + 0.1 * current_position
```

This becomes the triple cascade: position P → velocity PI → pitch PD → current.

Only implement if Phase 1-3 don't solve drift sufficiently.

---

## Phase 5: ROS2 Integration (Story 2.8)

Once balancing + velocity + yaw + joystick are solid:

1. `/cmd_vel` subscriber → `setDesiredVelocity(linear.x)`, `setYawRate(angular.z)`
2. ODrive position → `/odom` publisher (wheel odometry)
3. IMU pitch/roll/yaw/gyro → `/imu` publisher
4. Balance enable/disable via I2C command register

The velocity + yaw interface maps directly to `/cmd_vel`:
- Nav2 sends `linear.x` → velocity PI → pitch PD → current
- Nav2 sends `angular.z` → yaw PID → differential current
- Both combine at motor level: `left = pitch_torque + yaw_torque`, `right = pitch_torque - yaw_torque`

---

## Phase 6: Gazebo Simulation

URDF model, Gazebo world, ROS2 integration for testing navigation before hardware.

---

## Phase 7: Skate Park Test

Prerequisites: balance 60s+, velocity loop stable, yaw heading-hold, web joystick, AP mode WiFi.

---

## File Reference

| File | Purpose | Status |
|---|---|---|
| `modules/base/firmware/src/config.h` | All constants, PID defaults, velocity/yaw config | **Needs** vel filter alpha, yaw gains |
| `modules/base/firmware/src/balancing_controller.cpp` | Inner PID loop — uses `velController.getPitchOffset()` | Working |
| `modules/base/firmware/src/velocity_controller.cpp` | Outer velocity PI loop | **Needs** exponential smoothing |
| `modules/base/firmware/src/velocity_controller.h` | Velocity controller class definition | **Needs** filter state vars |
| `modules/base/firmware/src/yaw_controller.cpp` | Yaw heading-hold PID | **NEW — create** |
| `modules/base/firmware/src/yaw_controller.h` | Yaw controller class definition | **NEW — create** |
| `modules/base/firmware/src/odrive_uart.cpp` | ODrive UART — `readVelocity()` | **Needs** position parsing |
| `modules/base/firmware/src/motor_controller.cpp` | Torque mode, differential split (already has `left = bal + yaw`) | **Needs** yaw controller integration |
| `modules/base/firmware/src/web_tuner.cpp` | Web dashboard — sliders, charts, telemetry | **Needs** vel toggle, yaw sliders, joystick |
| `modules/base/firmware/src/imu.cpp` | BNO085 driver, gyro Y = pitch, gyro Z = yaw | **Check** if `getYaw()` exists |
| `modules/base/firmware/src/main.cpp` | Boot, state machine, loop | **Needs** yaw controller init/update |
| `modules/base/firmware/platformio.ini` | Build config, OTA settings | OK |

## Reference Projects

| Project | URL | What to take from it |
|---|---|---|
| mjbots hoverbot | https://github.com/mjbots/hoverbot | Architecture, gains, velocity filtering |
| RolfK redesign | https://www.hackster.io/RolfK/two-wheeled-self-balancing-robot-redesign-2077d9 | Twiddle auto-tuner, position hold migration |
| heethesh Balance-Bot | https://github.com/heethesh/Balance-Bot | Triple cascade reference for SLAM endgame |

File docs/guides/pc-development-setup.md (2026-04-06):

# PC Development Setup for OLAF

This guide explains how to set up your PC for OLAF development using a hybrid PC+Pi architecture. With this setup, you develop code on your PC, push via git, and deploy to the Raspberry Pi which handles all hardware control.

**When to use this guide:**
- Part of **Epic 0, Stories 0.2, 0.3, 0.4, 0.7**
- After Raspberry Pi setup is complete (Story 0.1)
- Before starting module development (Epic 1+)

---

## Overview: Hybrid PC+Pi Development Architecture

```
┌─────────────────────────────────────┐
│  YOUR PC (Development)              │
│  ┌───────────────────────────────┐  │
│  │ • Code editing (VS Code)      │  │
│  │ • Git push to deploy          │  │
│  │ • ros2 topic pub/echo         │  │
│  │ • rviz2, rqt visualization    │  │
│  │ • PlatformIO (ESP32 firmware) │  │
│  └───────────────────────────────┘  │
│           ↓ ROS2 DDS (WiFi)         │
│           ↓ ROS_DOMAIN_ID=42        │
└─────────────────────────────────────┘
            ↓
┌─────────────────────────────────────┐
│  RASPBERRY PI 5 (Hardware Control)  │
│  ┌───────────────────────────────┐  │
│  │ ROS2 Driver Nodes             │  │
│  │ • olaf_head (I2C 0x10)        │  │
│  │ • olaf_base (I2C 0x11)        │  │
│  │ • olaf_neck (USB Serial)      │  │
│  │ • olaf_ears (USB Serial)      │  │
│  │ • olaf_indicator (Fusion HAT) │  │
│  └───────────────────────────────┘  │
│           ↓                         │
└─────────────────────────────────────┘
            ↓
    ┌───────────────────────────────────────────────┐
    │ Hardware                                      │
    │ • Head ESP32 (0x10) → 2× GC9A01 OLED eyes    │
    │ • Base ESP32 (0x11) → BNO085 + ODrive       │
    │ • Waveshare Neck → 3× STS3215 servos         │
    │ • Waveshare Ears → 4× SCS0009 servos         │
    │ • Fusion HAT → WS2812 LEDs, kickstand PWM    │
    └───────────────────────────────────────────────┘
```

**Benefits:**
- ✅ Full IDE experience on PC (VS Code, debugging tools)
- ✅ Direct topic interaction with robot over WiFi
- ✅ No code duplication — same git repo on both machines
- ✅ Faster iteration (edit on PC, test via ROS2 topics)
- ✅ Better visualization tools (rviz2, rqt run better on PC)

---

## Prerequisites

### Hardware Requirements
- PC running Ubuntu 24.04 LTS
- Raspberry Pi 5 with OLAF setup complete
- Both PC and Pi on the same WiFi network

### Software Requirements
- Ubuntu 24.04 LTS (required for ROS2 Jazzy)
- Git
- Python 3.11+

---

## Installation Steps

### 1. Install ROS2 Jazzy on PC

```bash
# Set locale
sudo apt update && sudo apt install locales
sudo locale-gen en_US en_US.UTF-8
sudo update-locale LC_ALL=en_US.UTF-8 LANG=en_US.UTF-8
export LANG=en_US.UTF-8

# Add ROS2 apt repository
sudo apt install software-properties-common
sudo add-apt-repository universe
sudo apt update && sudo apt install curl -y
sudo curl -sSL https://raw.githubusercontent.com/ros/rosdistro/master/ros.key -o /usr/share/keyrings/ros-archive-keyring.gpg
echo "deb [arch=$(dpkg --print-architecture) signed-by=/usr/share/keyrings/ros-archive-keyring.gpg] http://packages.ros.org/ros2/ubuntu $(. /etc/os-release && echo $UBUNTU_CODENAME) main" | sudo tee /etc/apt/sources.list.d/ros2.list > /dev/null

# Install ROS2 Jazzy Desktop (includes rviz2, rqt, etc.)
sudo apt update
sudo apt install ros-jazzy-desktop -y

# Install development tools
sudo apt install python3-colcon-common-extensions python3-rosdep -y

# Initialize rosdep
sudo rosdep init
rosdep update
```

### 2. Configure ROS2 Environment

```bash
# Add to ~/.bashrc
echo "source /opt/ros/jazzy/setup.bash" >> ~/.bashrc
echo "export ROS_DOMAIN_ID=42" >> ~/.bashrc
echo "export ROS_LOCALHOST_ONLY=0" >> ~/.bashrc

# Source immediately
source ~/.bashrc
```

**IMPORTANT:** The `ROS_DOMAIN_ID=42` must match your Raspberry Pi.

### 3. Clone OLAF Repository

Clone directly to home directory (same structure as Pi):

```bash
cd ~
git clone https://github.com/kamalkantsingh10/OLAF.git olaf
```

Note: Use HTTPS for simplicity. For SSH (passwordless push): `git clone git@github.com:kamalkantsingh10/OLAF.git olaf`

### 4. Install Python Dependencies

```bash
pip install smbus2 pyserial numpy
```

### 5. Build ROS2 Workspace

```bash
cd ~/olaf/ros2

# Install ROS2 package dependencies
rosdep install --from-paths src --ignore-src -r -y

# Build workspace
colcon build --symlink-install

# Source the workspace
source install/setup.bash

# Add to ~/.bashrc for automatic sourcing
echo "source ~/olaf/ros2/install/setup.bash" >> ~/.bashrc
```

---

## Network Configuration

### 1. Verify ROS2 Domain ID (Both PC and Pi)

```bash
# On PC
echo $ROS_DOMAIN_ID  # Should be 42

# On Pi
ssh kamal@olaf.local "echo \$ROS_DOMAIN_ID"  # Should be 42
```

### 2. Configure Firewall (PC)

```bash
# Allow ROS2 DDS ports
sudo ufw allow 7400:7500/udp
sudo ufw allow 7400:7500/tcp

# Or disable firewall for local network (trusted networks only)
sudo ufw disable
```

### 3. Verify Network Connectivity

```bash
# Ping Pi from PC
ping olaf.local

# Test ROS2 cross-machine communication
# On Pi: Start a talker
ssh kamal@olaf.local "ros2 run demo_nodes_cpp talker"

# On PC: Listen (should see messages)
ros2 topic echo /chatter
```

---

## Development Workflow

### Git-Based Deployment

```
┌──────────────────────────────────────────────────────────────┐
│  1. EDIT on PC                                               │
│     code ~/olaf/ros2/src/olaf_head/                          │
│                          ↓                                   │
│  2. COMMIT & PUSH                                            │
│     cd ~/olaf && git add . && git commit -m "feat: ..." && git push │
│                          ↓                                   │
│  3. PULL on Pi                                               │
│     ssh kamal@olaf.local "cd ~/olaf && git pull"             │
│                          ↓                                   │
│  4. BUILD on Pi                                              │
│     ssh kamal@olaf.local "cd ~/olaf/ros2 && colcon build"    │
│                          ↓                                   │
│  5. RUN on Pi                                                │
│     ssh kamal@olaf.local "ros2 run olaf_head head_driver"    │
│                          ↓                                   │
│  6. INTERACT from PC                                         │
│     ros2 topic pub /head/expression ...                      │
└──────────────────────────────────────────────────────────────┘
```

### Quick Deploy Script

Create `~/olaf/scripts/deploy.sh`:

```bash
#!/bin/bash
set -e

PI_HOST="kamal@olaf.local"

echo "=== Deploying to Pi ==="

echo "1. Pulling latest code on Pi..."
ssh ${PI_HOST} "cd ~/olaf && git pull"

echo "2. Building on Pi..."
ssh ${PI_HOST} "cd ~/olaf/ros2 && source /opt/ros/jazzy/setup.bash && colcon build"

echo "=== Deploy complete ==="
echo "Run nodes with: ssh ${PI_HOST} 'cd ~/olaf/ros2 && source install/setup.bash && ros2 run ...'"
```

Make executable: `chmod +x scripts/deploy.sh`

### Daily Development Workflow

**Terminal 1 — Pi Driver Nodes:**
```bash
ssh kamal@olaf.local
cd ~/olaf_ws && source install/setup.bash
ros2 launch olaf_bringup drivers.launch.py
```

**Terminal 2 — PC Topic Interaction:**
```bash
# List available topics
ros2 topic list

# Send expression command to Head
ros2 topic pub /head/expression olaf_interfaces/msg/Expression "{emotion: 1, intensity: 3}" --once

# Echo sensor data from Base
ros2 topic echo /base/imu
```

**Terminal 3 — PC Visualization:**
```bash
rqt_graph  # View node connections
rqt        # All-in-one dashboard
```

---

## ESP32 Firmware Development on PC

### 1. Install PlatformIO

```bash
# Install PlatformIO Core
pip install platformio

# Add udev rules for ESP32
curl -fsSL https://raw.githubusercontent.com/platformio/platformio-core/develop/platformio/assets/system/99-platformio-udev.rules | sudo tee /etc/udev/rules.d/99-platformio-udev.rules
sudo udevadm control --reload-rules && sudo udevadm trigger

# Add user to dialout group
sudo usermod -aG dialout $USER
# Log out and back in
```

### 2. Build and Upload Firmware

```bash
# Head module (ESP32, I2C 0x10)
cd ~/olaf/modules/head/firmware
pio run                      # Build
pio run --target upload      # Upload (ESP32 connected to PC via USB)
pio device monitor           # Serial monitor

# Base module (ESP32, I2C 0x11)
cd ~/olaf/modules/base/firmware
pio run --target upload
```

---

## ROS2 Topic Reference

### Head Module (I2C 0x10)
```bash
# Subscribe topics (Pi → Head ESP32)
/head/expression    # Set eye expression
/head/blink         # Trigger blink
/head/look          # Set look direction

# Example
ros2 topic pub /head/expression olaf_interfaces/msg/Expression "{emotion: 1, intensity: 3}" --once
```

### Base Module (I2C 0x11)
```bash
# Subscribe topics (Pi → Base ESP32)
/cmd_vel            # Velocity commands (geometry_msgs/Twist)

# Publish topics (Base ESP32 → Pi)
/odom               # Odometry
/imu                # IMU data

# Example
ros2 topic pub /cmd_vel geometry_msgs/msg/Twist "{linear: {x: 0.1}, angular: {z: 0.0}}" --once
```

### Neck Module (USB Serial)
```bash
/neck/pose          # Set pan/tilt/roll angles
/neck/lookat        # Look at point in space

# Example
ros2 topic pub /neck/pose olaf_interfaces/msg/NeckPose "{pan: 30.0, tilt: 15.0, roll: 0.0}" --once
```

### Ears Module (USB Serial)
```bash
/ears/emote         # Preset emotions
/ears/pose          # Direct servo angles

# Example
ros2 topic pub /ears/emote std_msgs/msg/String "data: 'alert'" --once
```

### Indicator Module (Fusion HAT)
```bash
/indicator/interact # Interaction feedback LEDs
/indicator/status   # Status LEDs
/indicator/pid      # PID visualization LEDs

# Example
ros2 topic pub /indicator/status std_msgs/msg/String "data: 'success'" --once
```

---

## Monitoring and Debugging Tools

### RQt Tools (run on PC)

```bash
rqt_graph           # Visualize node connections
rqt_topic           # Monitor topics
rqt_console         # View logs
rqt_plot            # Plot numeric data
rqt                 # All-in-one dashboard
```

### Command-Line Tools

```bash
ros2 topic list                          # List all topics
ros2 topic echo /head/expression         # Monitor topic
ros2 topic info /head/expression         # Topic details
ros2 topic pub /head/blink std_msgs/msg/Bool "data: true" --once

ros2 node list                           # List all nodes
ros2 node info /olaf_head                # Node details

ros2 service list                        # List services
ros2 param list                          # List parameters
```

---

## Troubleshooting

### Issue: PC cannot see Pi's ROS2 topics

**Check 1: ROS_DOMAIN_ID matches**
```bash
# PC
echo $ROS_DOMAIN_ID  # Should be 42

# Pi
ssh kamal@olaf.local "echo \$ROS_DOMAIN_ID"  # Should be 42
```

**Check 2: Firewall**
```bash
sudo ufw allow 7400:7500/udp
sudo ufw allow 7400:7500/tcp
```

**Check 3: Network connectivity**
```bash
ping olaf.local
```

**Check 4: ROS_LOCALHOST_ONLY is disabled**
```bash
echo $ROS_LOCALHOST_ONLY  # Should be 0 or empty
```

### Issue: Permission denied when uploading to ESP32

```bash
sudo usermod -aG dialout $USER
# Log out and back in
```

### Issue: I2C errors on Pi

```bash
# Check I2C devices
ssh kamal@olaf.local "i2cdetect -y 1"
# Should show 0x10 (Head) and 0x11 (Base) when ESP32s connected
```

---

## Workspace Structure

Same structure on both PC and Pi — keeps things simple:

```
~/olaf/                             # Git repo (home base)
├── ros2/                           # ROS2 workspace
│   ├── src/
│   │   ├── olaf_bringup/           # Launch files
│   │   ├── olaf_interfaces/        # Custom messages
│   │   ├── olaf_head/              # Head driver node
│   │   ├── olaf_base/              # Base driver node
│   │   ├── olaf_neck/              # Neck driver node
│   │   ├── olaf_ears/              # Ears driver node
│   │   └── olaf_indicator/         # LED driver node
│   ├── build/                      # Colcon build output (gitignored)
│   ├── install/                    # Colcon install output (gitignored)
│   └── log/                        # Colcon logs (gitignored)
├── modules/
│   ├── head/
│   │   └── firmware/               # Head ESP32 firmware
│   └── base/
│       └── firmware/               # Base ESP32 firmware
├── docs/                           # Documentation
└── tools/                          # Diagnostic scripts
```

| Task | Directory |
|---|---|
| Git operations | `~/olaf/` |
| ROS2 build | `~/olaf/ros2/` |
| ESP32 firmware | `~/olaf/modules/{module}/firmware/` |

---

## Best Practices

1. **Always source workspace:**
   ```bash
   source ~/olaf_ws/install/setup.bash
   ```

2. **Use `--symlink-install` for faster Python iteration:**
   ```bash
   colcon build --symlink-install
   # Python changes don't require rebuild
   ```

3. **Build specific packages only:**
   ```bash
   colcon build --packages-select olaf_head
   ```

4. **Keep Pi drivers running, iterate via topics from PC**

5. **Use rqt_graph to visualize system state**

6. **Commit frequently, deploy often**

---

## Related Documentation

- **Story 0.1**: Install ROS2 on Pi — `docs/stories/0.1.install-ros2-jazzy.md`
- **Story 0.2**: Install ROS2 on PC — `docs/stories/0.2.install-ros2-pc.md`
- **Story 0.3**: Multi-machine networking — `docs/stories/0.3.configure-multi-machine-ros2.md`
- **Story 0.4**: Git workflow — `docs/stories/0.4.setup-git-workflow.md`
- **Story 0.7**: Dev tools on PC — `docs/stories/0.7.setup-dev-tools-pc.md`
- **Architecture**: `docs/architecture/tech-stack.md`
- **Coding Standards**: `docs/architecture/coding-standards.md`

---

**Last Updated:** 2026-02-01

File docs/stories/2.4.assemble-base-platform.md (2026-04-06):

# Story 2.4: Assemble Base Platform

## Status: In Progress

## Story

**As a** builder,
**I want** base platform assembled with motors, battery, and electronics,
**so that** I have a functional mobile base.

## Acceptance Criteria

1. Skateboard suspension/trucks mounted with hoverboard wheels
2. Battery mounted securely with access to charge port
3. ODrive and ESP32 mounted to platform
4. Power distribution wired and tested
5. All connections secure with proper cable management
6. Assembly documented in `modules/base/assembly.md`

## Tasks / Subtasks

- [x] Task 1: Prepare skateboard platform (AC: 1)
  - [x] Mount hoverboard trucks/suspension with hoverboard wheels on skateboard deck
  - [x] Verify wheel alignment and free rotation
  - [x] Test platform stability and weight capacity

- [x] Task 2: Mount battery securely (AC: 2)
  - [x] Design/select battery mounting bracket or enclosure
  - [x] Mount 36V hoverboard battery to platform with vibration dampening
  - [x] Ensure charge port is accessible from outside the enclosure
  - [x] Add battery disconnect switch (emergency stop)

- [x] Task 3: Wire power distribution (AC: 4)
  - [x] Wire 36V battery → ODrive (direct, via fuse + switch)
  - [x] Wire 36V → 12V buck converter (for servo power via Waveshare adapters)
  - [x] Wire 36V → 5V buck converter (for ESP32s and OLEDs)
  - [x] Verify all voltage rails with multimeter under load
  - [x] Add low-voltage cutoff protection if not built into BMS

- [ ] Task 4: Mount electronics (AC: 3)
  - [x] Mount ODrive v3.6 to platform with standoffs
  - [ ] Mount ESP32-S3-DevKitC-1 (N16R8) to platform with standoffs
  - [x] Mount buck converters securely
  - [x] Route motor phase wires from ODrive to hoverboard motors
  - [x] Connect Hall sensor cables from motors to ODrive

- [x] Task 5: Wire ESP32 connections (AC: 3, 4)
  - [x] Wire ESP32 to ODrive UART (GPIO 39=TX, GPIO 38=RX — J3 right header)
  - [x] Wire BNO085 IMU to ESP32 I2C0 (GPIO 4=SDA, GPIO 5=SCL), INT→GPIO 6, RST→GPIO 7
  - [ ] Wire I2C slave connection from ESP32 to Pi (GPIO 21=SDA, GPIO 47=SCL — J3 right header)
  - [x] Wire 5V power to ESP32 from 5V buck converter
  - [x] Wire 0.91" OLED (SSD1306) to ESP32 — GPIO 4 (SDA), GPIO 5 (SCL), 3.3V, GND

- [ ] Task 6: Cable management and connections (AC: 5)
  - [ ] Secure all wiring with cable ties and strain relief
  - [ ] Label all connectors and wires
  - [ ] Ensure no wires interfere with wheel rotation
  - [ ] Add connectors for quick-disconnect between torso and base

- [x] Task 7: Test complete assembly (AC: 4)
  - [x] Power on via battery switch — verify no shorts, no smoke
  - [x] Verify 36V, 12V, and 5V rails under load
  - [x] Verify ESP32 boots and BNO085 IMU initializes (serial monitor / OLED)
  - [x] Verify BNO085 I2C scan shows 0x4A
  - [x] Run BNO085 initial calibration: place robot stationary on flat surface for ~30s (accel/gyro auto-calibrate), then rotate slowly in figure-8 for magnetometer
  - [x] Verify BNO085 reports stable euler angles on OLED (pitch near 0° when upright)
  - [x] Verify ODrive powers up (green LED)
  - [x] Test emergency stop kills all power

- [ ] Task 8: Document assembly (AC: 6)
  - [ ] Update `modules/base/assembly.md` with step-by-step instructions
  - [ ] Include photos of completed assembly
  - [x] Document wiring connections in `modules/base/wiring.md`
  - [ ] Update `modules/base/README.md` with component list and specifications

## Dev Notes

### Platform Design

The base uses a skateboard deck as the structural platform with hoverboard trucks/wheels providing the two-wheel configuration needed for self-balancing. This is a hardware assembly story — no firmware or software work.

### Existing Hardware (from Stories 2.1-2.3)

- 2× hoverboard BLDC motors (~350W each, 6.5" wheels) — extracted in Story 2.1
- 36V battery pack — extracted and tested in Story 2.1
- ESP32 breadboard with BNO085 IMU — validated in Story 2.2
- ODrive v3.6 — tested with motors in Story 2.2
- Power distribution design — completed in Story 2.3

### ESP32 Board

**ESP32-S3-DevKitC-1 (N16R8)** — same board type as the Head module. Dual-core Xtensa LX7 @ 240MHz, 16MB flash, 8MB PSRAM.

### Pin Assignments (from platformio.ini / wiring.md)

| Function | GPIO | Notes |
|---|---|---|
| IMU SDA (I2C0 Master) | 4 | BNO085 + OLED shared bus |
| IMU SCL (I2C0 Master) | 5 | BNO085 + OLED shared bus |
| BNO085 INT | 6 | Data-ready interrupt (active low) |
| BNO085 RST | 7 | Hardware reset (active low, pulled high) |
| Pi SDA (I2C1 Slave) | 21 | J3 right header |
| Pi SCL (I2C1 Slave) | 47 | J3 right header |
| ODrive TX | 39 | J3 right header |
| ODrive RX | 38 | J3 right header |

### Power Architecture (from Story 2.3)

| Rail | Source | Loads |
|---|---|---|
| 36V direct | Battery | ODrive + BLDC motors |
| 12V | 36V→12V buck | Servo power via Waveshare adapters (neck, ears) |
| 5V | 36V→5V buck | ESP32 (Head, Base), OLED eyes |

### Safety

- Fuse between battery and ODrive (rated for motor stall current)
- Emergency stop switch cuts battery power
- Low-voltage cutoff at ~30V (prevents battery damage)

### File Locations

- Assembly guide: `modules/base/assembly.md`
- Wiring reference: `modules/base/wiring.md`
- README: `modules/base/README.md`

### Testing

This is a hardware assembly story. Testing is manual verification:
- Visual inspection of all connections
- Multimeter measurements of voltage rails
- Serial monitor confirmation of ESP32 + IMU boot
- ODrive power-on verification

No automated tests required.

## Change Log

| Date | Version | Description | Author |
|---|---|---|---|
| 2026-02-20 | 1.0 | Initial story creation for Epic 2 | Sarah (PO Agent) |

---

## Dev Agent Record

### Agent Model Used
<!-- To be filled by dev agent -->

### Debug Log References
<!-- To be filled by dev agent -->

### Completion Notes List
<!-- To be filled by dev agent -->

### File List
<!-- To be filled by dev agent -->

---

## QA Results
<!-- Results from QA Agent review of the completed story implementation -->

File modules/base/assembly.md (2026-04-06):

# Base Module Assembly

## Components

- ESP32-S3-DevKitC-1 (N16R8)
- BNO085 IMU (GY-BNO085 breakout)
- SSD1306 OLED (0.91" 128x32, I2C)
- ODrive v3.6 motor controller
- 2x Hoverboard BLDC motors (15 pole pairs, hall sensors)
- 36V hoverboard battery
- 36V→5V buck converter (ESP32 power)
- 36V→12V buck converter (servo power)

## Firmware Architecture

```
main.cpp                 — Boot sequence, state machine, serial commands
├── display_driver       — OLED init, messages, 3D wireframe HUD
├── motor_controller     — Enable/disable, balance/linear/turn, safety, auto-recover, calibration
│   └── odrive_uart      — Raw UART ASCII protocol (send/read only)
├── imu                  — BNO085 euler angles at 200Hz (on-chip AHRS)
└── config.h             — All constants (pins, PID gains, safety thresholds, velocity limits)
```

### Source Files

| File | Purpose |
|---|---|
| `src/main.cpp` | Boot sequence, state machine, serial command handler (CALIBRATE/PIDTEST/STOP) |
| `src/config.h` | Pin assignments, PID constants, safety thresholds, velocity limits |
| `src/motor_controller.h/cpp` | High-level motor interface for PID and navigation |
| `src/odrive_uart.h/cpp` | Low-level ODrive UART ASCII protocol |
| `src/display_driver.h/cpp` | SSD1306 OLED display, messages, real-time HUD |
| `src/imu.h/cpp` | BNO085 IMU driver, euler angles, accuracy reporting |

### MotorController Interface

```cpp
motors.begin();                          // Init ODrive UART
motors.enable();                         // Enter closed-loop control
motors.disable();                        // Idle mode
motors.emergencyStop();                  // Zero velocity + disable

motors.setBalanceVelocity(vel_revs);     // PID pitch correction (both wheels)
motors.setLinearVelocity(mps);           // Forward/backward (navigation/joystick)
motors.setTurnRate(radps);               // Differential steering (navigation/joystick)

motors.update(current_pitch_deg);        // Apply velocities + safety check (call every loop)
motors.calibrate();                      // Full calibration sequence (blocking)

motors.isReady();                        // No errors
motors.isEnabled();                      // Closed-loop active
motors.isSafetyTripped();                // Tilt exceeded threshold
motors.hasError(err0, err1);             // Read ODrive error registers
motors.getAxisVelocity(axis);            // Last commanded velocity
```

### Safety System

- **Emergency stop**: pitch exceeds 45° → motors disabled immediately
- **Auto-recover**: pitch stays below 30° for 1 second → motors re-enable
- **Velocity clamping**: all outputs clamped to ±10 rev/s (ODrive limit)
- **Navigation limits**: linear ±1.0 m/s, turn ±2.0 rad/s

### Serial Commands

| Command | Action |
|---|---|
| `CALIBRATE` | Clear errors, run full calibration on both axes, save pre_calibrated |
| `PIDTEST` | P-only balance test with 20Hz CSV telemetry |
| `STOP` | Zero velocity, disable motors |

### ODrive Setup (One-Time)

1. Connect ODrive via USB to PC
2. Run `poetry run python tools/diagnostics/odrive_test_and_calibrate.py`
3. Script configures motor params, calibrates, tests velocity, saves pre_calibrated
4. Future power-ups skip calibration (pre_calibrated flag)

See `modules/base/wiring.md` for full wiring reference and ODrive configuration values.

## Assembly Steps

[To be documented]

## Testing

[To be documented]

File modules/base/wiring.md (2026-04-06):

# Base Module Wiring Guide

## Overview

Complete wiring reference for the OLAF base platform. Covers power distribution from the 36V hoverboard battery through all voltage rails, ODrive motor controller connections, ESP32 (ESP32-S3-DevKitC-1) sensor and communication wiring.

---

## Power Distribution

### Power Rails

| Rail | Source | Converter | Loads |
|---|---|---|---|
| 36V | Battery direct | None (fuse + switch) | ODrive v3.6 + 2× BLDC motors |
| 12V | 36V battery | 36V→12V buck | Servo power via Waveshare adapters (neck, ears) |
| 5V | 36V battery | 36V→5V buck | ESP32 (Head, Base), OLED eyes |

### Battery → Main Switch → Fuse

```
36V Battery (+) ──→ Emergency Stop Switch ──→ Fuse ──→ Power Bus (+)
36V Battery (-) ──→ Power Bus (-)
```

- **Emergency stop switch**: Cuts ALL power when pressed
- **Fuse**: Rated for motor stall current (check ODrive + motor specs)

### 36V Rail (ODrive)

```
Power Bus (+) ──→ ODrive DC+ terminal
Power Bus (-) ──→ ODrive DC- terminal
```

- Direct 36V — no conversion needed
- ODrive powers both BLDC motors from its motor output terminals

### 36V → 12V Buck Converter

```
Power Bus (+) ──→ 12V Buck IN+
Power Bus (-) ──→ 12V Buck IN-
12V Buck OUT+ ──→ Waveshare Adapter power (neck + ears)
12V Buck OUT- ──→ Waveshare Adapter GND
```

- Verify output is 12V with multimeter before connecting loads
- Powers Feetech STS3215 (neck) and SCS0009 (ear) servos via Waveshare Bus Servo Adapters

### 36V → 5V Buck Converter

```
Power Bus (+) ──→ 5V Buck IN+
Power Bus (-) ──→ 5V Buck IN-
5V Buck OUT+ ──→ ESP32 5V / OLED 5V
5V Buck OUT- ──→ ESP32 GND / OLED GND
```

- Verify output is 5V with multimeter before connecting loads
- Powers Base ESP32, Head ESP32, and OLED eye displays

---

## ODrive v3.6 Connections

### Motor Phase Wires

| ODrive Terminal | Connection | Notes |
|---|---|---|
| M0 (A, B, C) | Left hoverboard motor phase wires | Match phase order — swap any 2 to reverse direction |
| M1 (A, B, C) | Right hoverboard motor phase wires | Match phase order — swap any 2 to reverse direction |

### Hall Sensor Cables

Each hoverboard motor has a 5-wire Hall sensor cable:

| Wire | ODrive Pin | Function |
|---|---|---|
| Red | 5V | Hall sensor power |
| Black | GND | Hall sensor ground |
| Yellow | Hall A | Encoder channel A |
| Green | Hall B | Encoder channel B |
| Blue | Hall C | Encoder channel C |

> **Note:** Wire colors may vary by motor manufacturer. Verify with multimeter or motor datasheet. Connect to ODrive M0/M1 encoder ports respectively.

### UART to ESP32

| ODrive Pin | ESP32 GPIO | Function |
|---|---|---|
| TX (GPIO 1) | GPIO 38 (RX) | ODrive transmit → ESP32 receive |
| RX (GPIO 2) | GPIO 39 (TX) | ESP32 transmit → ODrive receive |
| GND | GND | Common ground |

- Uses ODrive's UART interface for velocity commands and odometry feedback
- Baud rate: 115200 (ODrive default)
- Pins on J3 (right header) for easier screw-terminal wiring

---

## ESP32 (ESP32-S3-DevKitC-1) Pin Assignments

### Summary Table

| Function | GPIO | Bus | Direction | Notes |
|---|---|-----|---|---|
| I2C0 SDA (IMU + OLED) | 4 | I2C0 (Master) | Bidirectional | Shared: BNO085 (0x4A) + SSD1306 (0x3C) |
| I2C0 SCL (IMU + OLED) | 5 | I2C0 (Master) | Clock | Shared: BNO085 (0x4A) + SSD1306 (0x3C) |
| BNO085 INT | 6 | GPIO | Input (active low) | Data-ready interrupt — avoids polling at 200Hz |
| BNO085 RST | 7 | GPIO | Output (active low) | Hardware reset — recovery from hangs |
| Pi SDA | 21 | I2C1 (Slave) | Bidirectional | J3 right header, near USB pins |
| Pi SCL | 47 | I2C1 (Slave) | Clock | J3 right header, near USB pins |
| ODrive TX | 39 | UART | TX | ESP32 → ODrive (J3 right header) |
| ODrive RX | 38 | UART | RX | ODrive → ESP32 (J3 right header) |

### I2C0 Master Bus — IMU + OLED (GPIO 4/5, Shared)

Both devices share one I2C bus on GPIO 4/5. Different addresses, no conflict.

**BNO085 (GY-BNO085 breakout):**

| ESP32 GPIO | BNO085 Pin | Notes |
|---|---|---|
| GPIO 4 | SDA | Shared I2C0 bus |
| GPIO 5 | SCL | Shared I2C0 bus |
| GPIO 6 | INT | Data-ready interrupt (active low) — connect for 200Hz operation |
| GPIO 7 | RST | Hardware reset (active low) — pull high via 10kΩ, ESP32 drives low to reset |
| 3.3V | VIN | Power from ESP32 3.3V regulator |
| GND | GND | Common ground |
| 3.3V | CS | Tie HIGH — deselects SPI, required for I2C mode |
| GND | PS0 | Tie to GND — selects I2C protocol (PS0=LOW + PS1=LOW = I2C) |
| GND | PS1 | Tie to GND — selects I2C protocol |
| GND | AD0 | Tie to GND — sets I2C address to 0x4A |

**SSD1306 OLED (0.91"):**

| ESP32 GPIO | OLED Pin | Notes |
|---|---|---|
| GPIO 4 | SDA | Shared I2C0 bus |
| GPIO 5 | SCL | Shared I2C0 bus |
| 3.3V | VCC | Power from ESP32 3.3V regulator |
| GND | GND | Common ground |

**Bus Notes:**
- **IMU:** BNO085 (GY-BNO085 breakout) — 9-axis AHRS with on-chip Hillcrest SH-2 sensor fusion
- **IMU address:** 0x4A (default, AD0 low). Alternate: 0x4B (AD0 high)
- **OLED address:** 0x3C (default) — verify with I2C scan, some boards use 0x3D
- **I2C speed:** 400kHz (fast mode)
- **Pull-ups:** On-board (GY-BNO085 breakout has built-in pull-ups) — do NOT add external pull-ups
- **INT pin:** BNO085 asserts INT low when new sensor data is ready. Use GPIO interrupt on ESP32 to read at exactly 200Hz without polling. Configure as `INPUT_PULLUP` on ESP32 side.
- **RST pin:** Drive low for >10µs to hardware-reset BNO085. Useful for recovery if sensor hangs. Default: pulled high (running).
- **BNO085 outputs:** Rotation vector (quaternion), euler angles, linear acceleration, gyro — no complementary filter needed on ESP32
- **Library:** Adafruit_BNO08x (Arduino)
- **OLED refresh:** Update at 10Hz max — do NOT call inside 200Hz PID loop
- **OLED mounting:** Back of base platform, facing rearward for PID tuning visibility
- **Init:** `Wire.begin(4, 5);`

### Pi Communication — I2C1 Slave Bus

| ESP32 GPIO | Pi Pin | Notes |
|---|---|---|
| GPIO 21 | SDA (Pi I2C1) | J3-18, right header near USB pins |
| GPIO 47 | SCL (Pi I2C1) | J3-17, right header near USB pins |
| GND | GND | Common ground |

- **Slave address:** 0x0B (Base module)
- **Pins on J3 (right header)** for easier screw-terminal wiring alongside ODrive UART
- **Level shifting:** ESP32-S3 is 3.3V, Pi is 3.3V — no level shifter needed

### ESP32 Power

| Source | ESP32 Pin | Notes |
|---|---|---|
| 5V Buck OUT+ | 5V / VIN | Check board pinout for correct 5V input pin |
| 5V Buck OUT- | GND | Common ground |

---

## ODrive v3.6 Software Setup

### Prerequisites

- ODrive connected via USB to PC
- `odrive` Python package installed (in project poetry env)
- 36V battery connected and switched on
- **Wheels off ground** for calibration (motors will spin)

### 1. Configure Motor & Encoder Parameters

Run via `poetry run python3` or `odrivetool`:

```python
import odrive
from odrive.enums import *

odrv0 = odrive.find_any(timeout=10)

for i in [0, 1]:
    ax = getattr(odrv0, f'axis{i}')

    # Motor — hoverboard BLDC, 15 pole pairs
    ax.motor.config.pole_pairs = 15
    ax.motor.config.motor_type = MOTOR_TYPE_PMSM_CURRENT_CONTROL
    ax.motor.config.current_lim = 25                    # Amps
    ax.motor.config.calibration_current = 10             # Amps
    ax.motor.config.resistance_calib_max_voltage = 4     # Volts (low — hoverboard motors have low resistance)
    ax.motor.config.current_control_bandwidth = 100      # Hz
    ax.motor.config.torque_constant = 8.27 / 16          # KV=16, adjust if your motors differ

    # Encoder — built-in Hall sensors
    ax.encoder.config.mode = ENCODER_MODE_HALL
    ax.encoder.config.cpr = 90                           # pole_pairs × 6
    ax.encoder.config.calib_scan_distance = 150          # pulses
    ax.encoder.config.bandwidth = 100                    # Hz

    # Controller — velocity control for balancing
    ax.controller.config.control_mode = CONTROL_MODE_VELOCITY_CONTROL
    ax.controller.config.vel_limit = 10                  # turns/sec
    ax.controller.config.pos_gain = 1.0
    tc = ax.motor.config.torque_constant
    cpr = ax.encoder.config.cpr
    ax.controller.config.vel_gain = 0.02 * tc * cpr              # ~0.93
    ax.controller.config.vel_integrator_gain = 0.1 * tc * cpr    # ~4.65

odrv0.save_configuration()
odrv0.reboot()
```

### 2. Calibrate Both Motors

After reboot, reconnect and run calibration:

```python
odrv0 = odrive.find_any(timeout=10)

# Clear any errors
for i in [0, 1]:
    ax = getattr(odrv0, f'axis{i}')
    ax.error = 0
    ax.motor.error = 0
    ax.encoder.error = 0

# Calibrate each axis (motors will beep and spin)
for i in [0, 1]:
    ax = getattr(odrv0, f'axis{i}')
    ax.requested_state = AXIS_STATE_FULL_CALIBRATION_SEQUENCE
    while ax.current_state != AXIS_STATE_IDLE:
        time.sleep(0.5)
    assert ax.motor.error == 0, f"Axis {i} motor error: {ax.motor.error}"
    assert ax.encoder.error == 0, f"Axis {i} encoder error: {ax.encoder.error}"
    print(f"Axis {i}: resistance={ax.motor.config.phase_resistance:.4f}Ω, inductance={ax.motor.config.phase_inductance:.6f}H")

# Mark pre-calibrated (skip calibration on future power-ups)
for i in [0, 1]:
    ax = getattr(odrv0, f'axis{i}')
    ax.motor.config.pre_calibrated = True
    ax.encoder.config.pre_calibrated = True

odrv0.save_configuration()
```

### 3. Verify Velocity Control

```python
odrv0 = odrive.find_any(timeout=10)

# Test axis 0
odrv0.axis0.requested_state = AXIS_STATE_CLOSED_LOOP_CONTROL
odrv0.axis0.controller.input_vel = 2    # 2 turns/sec forward
time.sleep(2)
print(f"Measured: {odrv0.axis0.encoder.vel_estimate:.2f} rev/s")  # Should be ~2.0
odrv0.axis0.controller.input_vel = 0
odrv0.axis0.requested_state = AXIS_STATE_IDLE
```

### UART Configuration

UART is enabled by default on ODrive v3.6 firmware 0.5.x:

| Parameter | Value |
|---|---|
| `enable_uart` | `True` (default) |
| `uart_baudrate` | `115200` (default) |
| TX pin | ODrive GPIO 1 (J3 right header) |
| RX pin | ODrive GPIO 2 (J3 right header) |

No additional UART configuration needed — GPIO 1/2 are hardwired as UART on v3.6.

**ESP32 UART protocol (ASCII):**

```
v 0 2.5\n          # Set axis0 velocity to 2.5 turns/sec
v 1 -2.5\n         # Set axis1 velocity to -2.5 turns/sec
f 0\n               # Request axis0 feedback → returns "pos vel\n"
w axis0.requested_state 8\n   # Enter closed-loop control (state 8)
```

### Reference Values (from calibration 2026-03-30)

| Parameter | Axis 0 (Left) | Axis 1 (Right) |
|---|---|---|
| Phase resistance | 0.2574 Ω | 0.2934 Ω |
| Phase inductance | 0.560 mH | 0.613 mH |
| Velocity tracking | ±0.01 rev/s error at 2 rev/s | ±0.01 rev/s error at 2 rev/s |
| Firmware | 0.5.1 | — |
| Battery voltage | 38.0V | — |

### Troubleshooting

| Issue | Cause | Fix |
|---|---|-----|
| `MOTOR_ERROR_PHASE_RESISTANCE_OUT_OF_RANGE` | `resistance_calib_max_voltage` too low | Increase from 4V to 6V, retry calibration |
| Motor doesn't spin during calibration | Phase wires disconnected or wrong order | Check A/B/C connections, swap any 2 to reverse |
| `ENCODER_ERROR_ILLEGAL_HALL_STATE` | Hall sensor wire loose or wrong order | Check 5-pin cable, verify with `encoder.hall_state` (should be 1-6) |
| Velocity tracking poor | Gains too low for load | Increase `vel_gain` by 50%, recalibrate |
| ODrive not found via USB | USB cable data-only or driver issue | Try different cable, check `lsusb` for ODrive |

---

## Safety Notes

1. **Always verify voltages with multimeter before connecting loads**
2. **Emergency stop switch** must cut battery power to all rails
3. **Fuse** protects against shorts — size for ODrive + motor stall current
4. **Never hot-swap motor phase wires** while ODrive is powered
5. **Low-voltage cutoff** at ~30V prevents battery over-discharge damage
6. **Common ground** — all GND connections must share a common ground reference
7. **Strain relief** — secure all wires with cable ties, especially motor phase wires which experience vibration

---

## Wiring Checklist

Use this checklist when assembling:

- [ ] Battery → E-stop switch → fuse → power bus
- [ ] Power bus → ODrive DC+/DC-
- [ ] Power bus → 12V buck converter input
- [ ] Power bus → 5V buck converter input
- [ ] 12V buck output verified at 12V
- [ ] 5V buck output verified at 5V
- [ ] ODrive M0 ← left motor phase wires (A, B, C)
- [ ] ODrive M1 ← right motor phase wires (A, B, C)
- [ ] ODrive M0 encoder ← left motor Hall sensors
- [ ] ODrive M1 encoder ← right motor Hall sensors
- [ ] ODrive UART TX → ESP32 GPIO 38 (RX)
- [ ] ODrive UART RX ← ESP32 GPIO 39 (TX)
- [ ] ODrive GND — ESP32 GND
- [ ] BNO085 SDA — ESP32 GPIO 4 (shared I2C0 bus)
- [ ] BNO085 SCL — ESP32 GPIO 5 (shared I2C0 bus)
- [ ] BNO085 INT — ESP32 GPIO 6 (data-ready interrupt)
- [ ] BNO085 RST — ESP32 GPIO 7 (hardware reset, pulled high)
- [ ] BNO085 VIN — 3.3V
- [ ] BNO085 GND — GND
- [ ] BNO085 CS — 3.3V (deselect SPI for I2C mode)
- [ ] BNO085 PS0 — GND (I2C mode)
- [ ] BNO085 PS1 — GND (I2C mode)
- [ ] BNO085 AD0 — GND (address 0x4A)
- [ ] OLED SDA — ESP32 GPIO 4 (shared I2C0 bus)
- [ ] OLED SCL — ESP32 GPIO 5 (shared I2C0 bus)
- [ ] OLED VCC — 3.3V
- [ ] OLED GND — common GND
- [ ] I2C scan confirms IMU (0x4A) + OLED (0x3C) on bus
- [ ] ESP32 5V/VIN — 5V buck output
- [ ] ESP32 GND — common GND
- [ ] All GNDs tied together (common ground)
- [ ] No wires near wheel rotation path

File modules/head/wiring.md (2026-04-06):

# Head Module Wiring

## Overview

ESP32-S3-DevKitC-1 (N16R8) controlling:
- 2x GC9A01 round OLED eye displays (SPI)
- 1x WS2812 8-LED strip (face status indicator)
- I2C slave connection to Raspberry Pi

## Wiring Diagram

```
                                    ESP32-S3-DevKitC-1 (N16R8)
                              ┌─────────────────────────────────────┐
                              │              USB-C                  │
                              │               ┌─┐                   │
                              │               └─┘                   │
        ┌─────────────────────┤ LEFT (J1)              RIGHT (J3)  ├─────────────────────┐
        │                     │                                     │                     │
        │    3V3 ─── [1]  [2] ─── 3V3                    GND ─── [1]  [2] ─── TX         │
        │    RST ─── [3]  [4] ─── GPIO4 ◄── WS2812      GPIO43     [3]  [4] ─── GPIO1 ──►│── Right Eye CS
        │         ─── [5]  [6] ─── GPIO5                GPIO44 RX  [5]  [6] ─── GPIO2 ──►│── Left Eye CS
        │         ─── [7]  [8] ─── GPIO6                GPIO42 ─── [7]  [8] ─── GPIO41 ─►│── RST (shared)
        │         ─── [9] [10] ─── GPIO7                GPIO41 ─── [9] [10] ─── GPIO40 ─►│── DC (shared)
        │        ─── [11] [12] ─── GPIO8 ◄── I2C Scc    GPIO40 ── [11] [12] ─── GPIO39 ─►│── MOSI (shared)
        │        ─── [13] [14] ─── GPIO3                GPIO39 ── [13] [14] ─── GPIO38 ─►│── SCLK (shared)
        │        ─── [15] [16] ─── GPIO9 ◄── I2C SCL    GPIO38 ── [15] [16] ─── GPIO37   │
        │        ─── [17] [18] ─── GPIO10               GPIO37 ── [17] [18] ─── GPIO36   │
        │        ─── [19] [20] ─── GPIO11               GPIO36 ── [19] [20] ─── GPIO0    │
        │        ─── [21] [22] ─── GPIO12               GPIO35 ── [21] [22] ─── GPIO45   │
        │         5V ─── [23] [24] ─── GND              GPIO48 ── [23] [24] ─── GPIO47   │
        │                     │                         GPIO21 ── [25] [26] ─── GND      │
        └─────────────────────┤                                     ├─────────────────────┘
                              │               ┌─┐                   │
                              │              BOOT                   │
                              └─────────────────────────────────────┘
```

## Pin Assignments

### I2C (to Raspberry Pi) - LEFT SIDE

| Function | GPIO | ESP32 Pin | Pi GPIO | Notes |
|---|---|---|---|---|
| I2C SDA  | 8 | J1-12 | GPIO 2  | 4.7kΩ pull-up to 3.3V |
| I2C SCL  | 9 | J1-15 | GPIO 3  | 4.7kΩ pull-up to 3.3V |

**I2C Address:** `0x08`

### WS2812 LED Strip - LEFT SIDE

| Function | GPIO | ESP32 Pin | Notes |
|---|---|---|---|
| DATA | 4 | J1-4 | Single wire, 3.3V logic OK for WS2812 |

### SPI Displays (Both Eyes) - RIGHT SIDE

| Function | GPIO | ESP32 Pin | Notes |
|---|---|---|---|
| SCLK | 38 | J3-10 | Shared clock |
| MOSI | 39 | J3-9 | Shared data |
| DC | 40 | J3-8 | Shared data/command |
| RST | 41 | J3-7 | Shared reset |
| CS Left  | 2 | J3-5 | Left eye chip select |
| CS Right | 1 | J3-4 | Right eye chip select |

## Component Wiring Details

### WS2812 8-LED Strip

```
    WS2812 Strip (8 LEDs)
    ┌─────────────────────────────────────────────────────────┐
    │  [0] [1] [2] [3] │ [4] [5] [6] [7]                      │
    │   ◄── LEFT ────    ──── RIGHT ──►                       │
    │       edges → center ← edges                            │
    ├─────────────────────────────────────────────────────────┤
    │  VCC ─────────────────────────► 5V (from buck converter)│
    │  GND ─────────────────────────► GND (common ground)     │
    │  DIN ─────────────────────────► GPIO4 (ESP32 J1-4)      │
    └─────────────────────────────────────────────────────────┘

    Note: WS2812 runs on 5V but accepts 3.3V logic from ESP32.
    For long runs (>30cm), add 300-500Ω resistor on data line.
```

### GC9A01 OLED Displays (x2)

```
    Left Eye (GC9A01)              Right Eye (GC9A01)
    ┌───────────────┐              ┌───────────────┐
    │ VCC ──► 3.3V  │              │ VCC ──► 3.3V  │
    │ GND ──► GND   │              │ GND ──► GND   │
    │ SCL ──► GPIO38│ (shared)     │ SCL ──► GPIO38│ (shared)
    │ SDA ──► GPIO39│ (shared)     │ SDA ──► GPIO39│ (shared)
    │ DC  ──► GPIO40│ (shared)     │ DC  ──► GPIO40│ (shared)
    │ RST ──► GPIO41│ (shared)     │ RST ──► GPIO41│ (shared)
    │ CS  ──► GPIO2 │ (unique)     │ CS  ──► GPIO1 │ (unique)
    │ BL  ──► 3.3V  │ (always on)  │ BL  ──► 3.3V  │ (always on)
    └───────────────┘              └───────────────┘
```

### I2C Connection to Raspberry Pi

```
    Raspberry Pi 5                    ESP32-S3
    ┌────────────────┐                ┌────────────────┐
    │                │                │                │
    │ GPIO 2 (SDA) ──┼───────────────►│ GPIO 8 (SDA)   │
    │                │                │                │
    │ GPIO 3 (SCL) ──┼───────────────►│ GPIO 9 (SCL)   │
    │                │                │                │
    │ GND ───────────┼───────────────►│ GND            │
    │                │                │                │
    └────────────────┘                └────────────────┘

    Note: Pi 5 has built-in 1.8kΩ pull-ups on SDA/SCL.
    No external pull-up resistors needed for runs <30cm.
```

## Power Distribution

```
    36V Battery
        │
        ▼
    ┌───────────────┐
    │ 36V→5V Buck   │
    └───────┬───────┘
            │ 5V
            ├──────────────────► ESP32 5V pin (J1-21)
            │
            └──────────────────► WS2812 VCC

    ESP32 Internal 3.3V Regulator
            │
            ├──────────────────► GC9A01 Left Eye VCC
            │
            └──────────────────► GC9A01 Right Eye VCC
```

## I2C Register Map

**Slave Address:** `0x08`

### Status Registers (Read-only)

| Register | Address | Description |
|---|---|---|
| STATUS | 0x00 | Module status (0x00=OK, 0x01=READY, 0x02=BUSY, 0x04=ERROR) |
| COMMAND | 0x01 | Reserved for future commands |
| MODULE_ID | 0x02 | Returns slave address (0x08) |
| FIRMWARE_VER | 0x03 | Firmware version byte |
| ERROR_CODE | 0x04 | Last error code |

### Expression Registers (Write)

| Register | Address | Values | Description |
|---|---|---|---|
| EXPRESSION_TYPE | 0x10 | 0-6 | 0=neutral, 1=happy, 2=sad, 3=surprised, 4=angry, 5=sleepy, 6=wink |
| EXPRESSION_INTENSITY | 0x11 | 1-5 | 1=subtle, 5=extreme |
| BLINK_TRIGGER | 0x12 | any | Write any value to trigger a blink |

### Look Direction Registers (Write)

| Register | Address | Values | Description |
|---|---|---|---|
| LOOK_X | 0x20 | -100 to +100 | Signed byte: negative=left, positive=right |
| LOOK_Y | 0x21 | -100 to +100 | Signed byte: negative=down, positive=up |

### System Status Register (Write)

| Register | Address | Values | Description |
|---|---|---|---|
| SYSTEM_STATUS | 0x30 | 0-5 | Controls eye wake state and LED strip animation |

### Quick Test Commands (from Pi)

```bash
# Detect device
i2cdetect -y 1          # Should show 0x08

# Wake eyes
i2cset -y 1 0x08 0x30 0x01   # WOKE_UP

# Set to speaking mode (required before expressions show)
i2cset -y 1 0x08 0x30 0x04   # SPEAKING

# Set expression
i2cset -y 1 0x08 0x10 0x01   # HAPPY

# Trigger blink
i2cset -y 1 0x08 0x12 0x01

# Look right
i2cset -y 1 0x08 0x20 0x64   # X = +100

# Look left (signed: -100 = 0x9C)
i2cset -y 1 0x08 0x20 0x9c

# Put to sleep
i2cset -y 1 0x08 0x30 0x05   # GOING_IDLE
```

## LED Strip States

| State | I2C Value | Animation |
|---|---|---|
| IDLE | 0x00 | Off |
| WOKE_UP | 0x01 | Edges sweep inward → flash |
| LISTENING | 0x02 | Blue pulse from center |
| PROCESSING | 0x03 | Chase toward center |
| SPEAKING | 0x04 | Rainbow colors popping |
| GOING_IDLE | 0x05 | Fade edges inward → off |

## Notes

1. **I2C Pull-ups:** Pi 5 has built-in 1.8kΩ pull-ups on GPIO 2/3 — sufficient for short runs (<30cm). External 4.7kΩ not required.
2. **WS2812 Data:** GPIO4 chosen for clean signal, no conflicts
3. **Display Backlight:** Connected directly to 3.3V (always on, no PWM control)
4. **Ground:** All components share common ground with ESP32
5. **Reserved GPIOs:** Do not use GPIO 26-32 (flash) or GPIO 33-37 (PSRAM)

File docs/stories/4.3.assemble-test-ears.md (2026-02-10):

# Story 4.3: Assemble and Test Ears Module

## Status: Done

## Story

**As a** builder,
**I want** ears assembled and tested,
**so that** ear articulation works expressively.

## Acceptance Criteria

1. Servos mounted in ear brackets
2. Ear shapes attached to servo horns
3. Full range of motion without interference
4. Both ears move symmetrically
5. Assembly documented in `modules/ears/assembly.md`

## Tasks / Subtasks

- [ ] Task 1: Prepare components (AC: 1)
  - [ ] Gather all 3D printed parts from Story 4.2
  - [ ] Gather 4× SCS0009 servos (IDs pre-assigned from Story 4.1)
  - [ ] Gather mounting hardware (M2/M2.5 screws, servo horns)
  - [ ] Gather servo cables (daisy-chain compatible)
  - [ ] Verify all parts are present before assembly

- [ ] Task 2: Assemble left ear (AC: 1, 2)
  - [ ] Mount base rotation servo (ID 1) in left ear bracket
  - [ ] Secure with screws
  - [ ] Attach servo horn adapter for second servo
  - [ ] Mount ear angle servo (ID 2) on adapter
  - [ ] Attach left ear shape to servo horn
  - [ ] Route cables for clean management

- [ ] Task 3: Assemble right ear (AC: 1, 2)
  - [ ] Mount base rotation servo (ID 3) in right ear bracket
  - [ ] Secure with screws
  - [ ] Attach servo horn adapter for second servo
  - [ ] Mount ear angle servo (ID 4) on adapter
  - [ ] Attach right ear shape to servo horn
  - [ ] Route cables for clean management

- [ ] Task 4: Test mechanical range of motion (AC: 3)
  - [ ] Manually move each servo through its range (power off)
  - [ ] Verify no binding or interference
  - [ ] Verify ear shape clears head enclosure at extremes
  - [ ] Verify servo cables have sufficient slack
  - [ ] Adjust brackets if interference found

- [ ] Task 5: Test powered motion (AC: 3, 4)
  - [ ] Connect ears to Waveshare adapter (daisy-chain)
  - [ ] Power on and run test script from Story 4.1
  - [ ] Move all servos to neutral position (512)
  - [ ] Test base rotation: sweep ±60°
  - [ ] Test ear angle: sweep ±45°
  - [ ] Verify smooth motion without stalling

- [ ] Task 6: Test symmetry (AC: 4)
  - [ ] Command both ears to same position
  - [ ] Verify visual symmetry
  - [ ] Test all expression presets (perked, alert, sad, happy, relaxed)
  - [ ] Measure and document any asymmetry
  - [ ] Adjust servo offsets if needed

- [ ] Task 7: Mount to head enclosure
  - [ ] Attach left ear assembly to head mounting points
  - [ ] Attach right ear assembly to head mounting points
  - [ ] Route cables through head to Waveshare adapter
  - [ ] Verify ears still have full range when mounted
  - [ ] Verify secure attachment under motion

- [ ] Task 8: Document assembly (AC: 5)
  - [ ] Update `modules/ears/assembly.md` with:
    - [ ] Step-by-step instructions with photos
    - [ ] Tools required
    - [ ] Troubleshooting tips
    - [ ] Servo offset calibration procedure
  - [ ] Update `modules/ears/README.md` with assembly status

## Dev Notes

### Assembly Order

1. **Pre-assembly check** - Verify all parts and tools
2. **Servo preparation** - Verify IDs, test individually
3. **Left ear assembly** - Base servo → adapter → angle servo → ear shape
4. **Right ear assembly** - Mirror of left
5. **Range testing** - Manual then powered
6. **Symmetry calibration** - Adjust offsets
7. **Head mounting** - Attach to enclosure
8. **Final test** - Full expression preset test

### Tools Required

- Small Phillips screwdriver (#0 or #1)
- Needle-nose pliers
- Wire cutters/strippers
- Hot glue gun (optional, for cable management)
- Multimeter (for debugging)

### Hardware BOM

| Item | Quantity | Notes |
|---|---|---|
| SCS0009 servo | 4 | IDs 1-4 pre-assigned |
| Servo horn | 4 | Included with servos |
| M2×6 screw | 16 | Servo mounting |
| M2.5×8 screw | 8 | Bracket mounting |
| Servo cable | 3 | Daisy-chain connections |

### Servo ID Reminder

| ID | Location | Function |
|----|---|---|
| 1 | Left ear | Base rotation |
| 2 | Left ear | Ear angle |
| 3 | Right ear | Base rotation |
| 4 | Right ear | Ear angle |

### Calibration Procedure

If ears are not symmetric:
1. Move both ears to neutral (512)
2. Measure visual offset
3. Adjust individual servo offsets in software
4. Store offsets in configuration file

```python
# Example offset configuration
EAR_OFFSETS = {
    1: 0,    # Left base (reference)
    2: 0,    # Left angle
    3: -5,   # Right base (adjusted for symmetry)
    4: 3,    # Right angle (adjusted for symmetry)
}
```

### Troubleshooting

**Servo not responding:**
- Verify ID is correct (use ping test)
- Check cable connections
- Verify power is adequate (6V recommended)

**Jerky motion:**
- Reduce speed parameter in write command
- Check for mechanical binding
- Verify servo is not overloaded

**Asymmetric movement:**
- Apply software offset correction
- Check if servo horns are installed at same angle
- Verify mounting is identical on both sides

### Source Tree

```
modules/ears/
├── hardware/
│   ├── 3d-models/    # From Story 4.2
│   └── bom/
│       └── ears-bom.csv
├── assembly.md       # Updated in this story
└── README.md
```

### Dependencies

- Story 4.1: Test Waveshare Adapter with SCS0009 Servos (must be complete)
- Story 4.2: Design Ear Mechanical Assembly (must be complete)
- Story 1.5: Design and 3D Print Head Enclosure (for mounting points)

### Testing

**Acceptance Test Script:**
```bash
# Run comprehensive ear test
python tools/diagnostics/test_ears_servos.py --full-test

# Expected output:
# Left ear - base rotation: PASS (range ±60°)
# Left ear - angle: PASS (range ±45°)
# Right ear - base rotation: PASS (range ±60°)
# Right ear - angle: PASS (range ±45°)
# Symmetry test: PASS (offset <5 counts)
# Expression presets: PASS (5/5 presets executed)
```

**Manual Verification:**
- Watch ears during expression test
- Verify no mechanical noise (grinding, clicking)
- Verify cables remain secure during motion

## Change Log

| Date | Version | Description | Author |
|---|---|---|---|
| 2026-02-07 | 1.0 | Initial story creation for Epic 4 | Sarah (PO Agent) |
| 2026-02-10 | 1.1 | Marked Done — ears assembled, tested, and mounted by builder | Dev Agent (Claude Opus 4.6) |

---

## Dev Agent Record

### Agent Model Used
<!-- Record the specific AI agent model and version used for development -->

### Debug Log References
<!-- Reference any debug logs or traces generated during development -->

### Completion Notes List
<!-- Notes about the completion of tasks and any issues encountered -->

### File List
<!-- List all files created, modified, or affected during story implementation -->

---

## QA Results
<!-- Results from QA Agent review of the completed story implementation -->

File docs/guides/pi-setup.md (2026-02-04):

# Raspberry Pi 5 Setup Guide for OLAF

Complete setup guide for the Raspberry Pi 5 as OLAF's orchestration layer. This guide covers:

- **Part 1-2**: Ubuntu 24.04 and ROS2 Jazzy installation
- **Part 3**: ROS2 workspace setup
- **Part 4**: I2C configuration for ESP32 modules
- **Part 5**: USB serial for Waveshare servo adapters
- **Part 6**: Basic Fusion HAT installation
- **Part 7**: Hailo-8L AI Kit setup (26 TOPS for local Whisper STT)
- **Part 8**: Detailed Fusion HAT configuration (WS2812, PWM, I2S)
- **Part 9**: Multi-machine ROS2 networking
- **Part 10**: Git configuration
- **Part 11**: Display rotation (optional)

**Related Stories:**
- Story 0.1: Install Ubuntu 24.04 and ROS2 Jazzy
- Story 0.3: Configure Multi-Machine ROS2 Networking
- Story 0.5: Configure Fusion HAT and I2C
- Story 0.6: Configure USB Serial for Waveshare Adapters

---

## Hardware Overview

The Raspberry Pi 5 serves as OLAF's brain, running ROS2 nodes that coordinate all robot subsystems. It communicates with hardware through multiple interfaces, with two HATs stacked on top providing AI acceleration and GPIO expansion.

```
┌─────────────────────────────────────────────────────────────┐
│              HARDWARE STACK (TOP TO BOTTOM)                 │
├─────────────────────────────────────────────────────────────┤
│  ┌───────────────────────────────────────────────────────┐  │
│  │   Hailo-8L AI HAT (26 TOPS)                           │  │
│  │   └─ Local Whisper STT (<200ms latency)               │  │
│  └───────────────────────────────────────────────────────┘  │
│                          ↓ PCIe                             │
│  ┌───────────────────────────────────────────────────────┐  │
│  │   Sunfounder Fusion HAT+                              │  │
│  │   ├─ WS2812 LEDs (24 indicator lights)                │  │
│  │   ├─ PWM (kickstand servos)                           │  │
│  │   └─ I2S Audio (speaker)                              │  │
│  └───────────────────────────────────────────────────────┘  │
│                          ↓ GPIO                             │
│  ┌───────────────────────────────────────────────────────┐  │
│  │   Raspberry Pi 5 (16GB)                               │  │
│  │   ├─ Ubuntu 24.04 LTS + ROS2 Jazzy                    │  │
│  │   ├─ I2C Bus → Head ESP32 (0x10), Base ESP32 (0x11)   │  │
│  │   └─ USB Serial → Waveshare Neck, Waveshare Ears      │  │
│  └───────────────────────────────────────────────────────┘  │
└─────────────────────────────────────────────────────────────┘
```

**Why this architecture?**
- **Hailo-8L**: Provides 26 TOPS of AI acceleration for local speech-to-text. No cloud latency, no privacy concerns, works offline.
- **Fusion HAT**: Pre-built GPIO expansion providing WS2812 LED control and PWM outputs without custom PCB work or soldering.
- **I2C**: Low-latency communication with ESP32s running real-time control loops (eye animations at 60fps, balancing PID at 200Hz)
- **USB Serial**: Reliable communication with Waveshare servo adapters — no soldering required, plug-and-play

---

## Part 1: Ubuntu 24.04 LTS Installation

We use Ubuntu 24.04 LTS instead of Raspberry Pi OS because ROS2 Jazzy (the latest long-term support release) has native packages for Ubuntu 24.04. This means easier installation and better compatibility with the ROS2 ecosystem.

### 1.1 Download and Flash

First, we need to create a bootable SD card with Ubuntu. The Raspberry Pi Imager tool makes this easy and lets us pre-configure WiFi and SSH so the Pi is accessible immediately on first boot.

1. **Download Ubuntu Server 24.04 LTS (64-bit)** for Raspberry Pi from:
   - https://ubuntu.com/download/raspberry-pi

2. **Install and run Raspberry Pi Imager** on your PC:
   ```bash
   sudo apt install rpi-imager
   rpi-imager
   ```

3. **Configure the image** in Raspberry Pi Imager:
   - Choose OS: Other general-purpose OS → Ubuntu → Ubuntu Server 24.04 LTS (64-bit)
   - Choose Storage: Select your SD card
   - Click the gear icon to configure:
     - Set hostname: `olaf`
     - Enable SSH with password authentication
     - Set username and password
     - Configure WiFi (SSID and password)
     - Set locale settings

4. **Write the image** and wait for verification to complete

5. **Insert the SD card** into your Pi 5 and power it on

The Pi will boot and automatically connect to your WiFi network. Give it about 2 minutes for the first boot to complete.

### 1.2 Initial Configuration

Now we'll SSH into the Pi and perform initial system configuration. These steps ensure the system is up-to-date and properly configured for development.

**Connect to the Pi via SSH:**
```bash
ssh kamal@olaf.local
```

If `olaf.local` doesn't resolve, find the Pi's IP address from your router and use that instead.

**Update the system packages:**

This downloads the latest package lists and upgrades all installed packages to their newest versions. Important for security and compatibility.

```bash
sudo apt update && sudo apt upgrade -y
```

**Fix locale settings:**

Ubuntu Server sometimes has incomplete locale configuration, which causes warning messages. These commands generate the proper locale files and set them as default.

```bash
sudo locale-gen en_US.UTF-8
sudo update-locale LC_ALL=en_US.UTF-8 LANG=en_US.UTF-8
echo 'export LANG=en_US.UTF-8' >> ~/.bashrc
source ~/.bashrc
```

**Set your timezone:**

Replace the timezone with your own (use `timedatectl list-timezones` to see options).

```bash
sudo timedatectl set-timezone America/Los_Angeles
```

---

## Part 2: ROS2 Jazzy Installation

ROS2 (Robot Operating System 2) is the middleware framework that enables all OLAF's subsystems to communicate. We're using Jazzy Jalisco, the latest LTS release supported until 2029.

ROS2 provides:
- **Pub/Sub messaging**: Nodes publish and subscribe to topics (e.g., `/head/expression`)
- **Services**: Request/response patterns for commands
- **Actions**: Long-running tasks with feedback
- **Launch system**: Start multiple nodes with one command
- **Ecosystem**: Navigation, visualization, and debugging tools

### 2.1 Add ROS2 Repository

ROS2 isn't in Ubuntu's default repositories, so we need to add the official ROS2 package repository. This involves adding a GPG key (to verify package authenticity) and the repository URL.

**Install prerequisite tools:**
```bash
sudo apt install -y software-properties-common curl
```

**Add the ROS2 GPG key:**

This key verifies that packages actually come from the ROS2 project and haven't been tampered with.

```bash
sudo curl -sSL https://raw.githubusercontent.com/ros/rosdistro/master/ros.key -o /usr/share/keyrings/ros-archive-keyring.gpg
```

**Add the ROS2 repository:**

This command constructs the correct repository URL for your Ubuntu version and adds it to apt's sources.

```bash
echo "deb [arch=$(dpkg --print-architecture) signed-by=/usr/share/keyrings/ros-archive-keyring.gpg] http://packages.ros.org/ros2/ubuntu $(. /etc/os-release && echo $UBUNTU_CODENAME) main" | sudo tee /etc/apt/sources.list.d/ros2.list > /dev/null
```

### 2.2 Install ROS2 Jazzy

Now we can install ROS2. We're installing `ros-jazzy-ros-base` (not `desktop`) because the Pi doesn't need GUI tools — those run on your development PC.

**Update apt and install ROS2:**
```bash
sudo apt update
sudo apt install -y ros-jazzy-ros-base
```

**Install development tools:**

- `colcon`: The build tool for ROS2 workspaces
- `rosdep`: Automatically installs dependencies for ROS2 packages
- `pip`: Python package manager for additional libraries

```bash
sudo apt install -y python3-colcon-common-extensions python3-rosdep python3-pip
```

**Initialize rosdep:**

rosdep maintains a database of system dependencies for ROS2 packages. We need to initialize it once.

```bash
sudo rosdep init
rosdep update
```

### 2.3 Configure ROS2 Environment

Every terminal session needs to "source" ROS2's setup script to access ROS2 commands. We'll add this to `.bashrc` so it happens automatically.

We also set two important environment variables:
- `ROS_DOMAIN_ID=42`: Isolates our robot's traffic from other ROS2 systems on the network. All machines communicating must use the same ID.
- `ROS_LOCALHOST_ONLY=0`: Allows ROS2 to communicate across the network (not just localhost).

```bash
echo "" >> ~/.bashrc
echo "# ROS2 Jazzy" >> ~/.bashrc
echo "source /opt/ros/jazzy/setup.bash" >> ~/.bashrc
echo "export ROS_DOMAIN_ID=42" >> ~/.bashrc
echo "export ROS_LOCALHOST_ONLY=0" >> ~/.bashrc

source ~/.bashrc
```

### 2.4 Verify ROS2 Installation

Let's confirm ROS2 is working properly:

```bash
echo $ROS_DISTRO
```
Expected output: `jazzy`

```bash
ros2 topic list
```
Expected output: `/parameter_events` and `/rosout` (default topics that always exist)

```bash
ros2 doctor --report
```
This shows detailed system information about your ROS2 installation.

---

## Part 3: ROS2 Workspace Setup

Since this Pi is dedicated to OLAF, we'll use a simple structure: clone the repository directly to `~/olaf/` and use the `ros2/` subdirectory as the colcon workspace.

### 3.1 Clone Repository

Clone the OLAF repository directly to your home directory:

```bash
cd ~
git clone https://github.com/kamalkantsingh10/OLAF.git olaf
```

Note: We use HTTPS for simplicity. If you prefer SSH (for passwordless push), set up SSH keys per Part 10, then use: `git clone git@github.com:kamalkantsingh10/OLAF.git olaf`

**Resulting structure:**
```
~/olaf/                    # Git repo (home base for everything)
├── ros2/
│   ├── src/               # ROS2 packages (olaf_head, olaf_base, etc.)
│   ├── build/             # colcon output (gitignored)
│   ├── install/           # colcon output (gitignored)
│   └── log/               # colcon output (gitignored)
├── modules/               # ESP32 firmware (head, base)
├── docs/                  # Documentation
└── tools/                 # Diagnostic scripts
```

### 3.2 Install Python Dependencies with Poetry

OLAF uses Poetry for Python dependency management. The root `pyproject.toml` defines all required packages including:
- `smbus2`: I2C communication with ESP32 modules
- `pyserial`: USB serial communication with Waveshare adapters
- `numpy`: Numerical operations for sensor processing
- `anthropic`, `openai`: AI integration
- `odrive`: Motor controller communication

**Install Poetry:**

```bash
curl -sSL https://install.python-poetry.org | python3 -
echo 'export PATH="$HOME/.local/bin:$PATH"' >> ~/.bashrc
source ~/.bashrc
```

**Verify Poetry installation:**

```bash
poetry --version
```

**Install Python dependencies:**

```bash
cd ~/olaf
poetry install
```

This creates a virtual environment and installs all dependencies from `pyproject.toml`.

**Note:** You may see a warning about `/home/kamal/olaf/orchestrator does not contain any element` — this is expected since the orchestrator package will be created in later stories.

### 3.3 Install ROS2 Dependencies

ROS2 packages declare their dependencies in `package.xml` files. The `rosdep` tool reads these and installs required system packages automatically.

```bash
cd ~/olaf/ros2
rosdep install --from-paths src --ignore-src -r -y
```

### 3.4 Build Workspace

`colcon build` compiles all packages in the workspace. Run it from the `ros2/` directory. The `--symlink-install` flag creates symbolic links instead of copying Python files, so you can edit code without rebuilding (for Python packages).

```bash
cd ~/olaf/ros2
colcon build --symlink-install
```

**Source the workspace:**

After building, we need to source the workspace's setup script to make the built packages available. We also add this to `.bashrc` for future sessions.

```bash
source install/setup.bash
echo "source ~/olaf/ros2/install/setup.bash" >> ~/.bashrc
```

### 3.5 Verify Build

Check that the OLAF packages are recognized:

```bash
ros2 pkg list | grep -E "olaf|driver"
```

**Expected output:**
```
base_driver
head_ears_driver
neck_driver
olaf_bringup
olaf_interfaces
torso_driver
```

If packages are missing, check build logs for errors:
```bash
cat log/latest_build/*/stdout_stderr.log | grep -i error
```

### 3.6 Directory Usage Summary

| Task | Directory |
|---|---|
| Git operations (pull, push, status) | `~/olaf/` |
| ROS2 build (`colcon build`) | `~/olaf/ros2/` |
| ROS2 run/launch | `~/olaf/ros2/` (after sourcing) |
| ESP32 firmware development | `~/olaf/modules/{module}/firmware/` |
| Documentation | `~/olaf/docs/` |

---

## Part 4: I2C Configuration (ESP32 Modules)

I2C (Inter-Integrated Circuit) is a two-wire serial protocol perfect for connecting multiple devices to the Pi. OLAF uses I2C for the two ESP32 modules that need real-time control:

| Module | I2C Address | Purpose |
|---|---|---|
| Head ESP32 | `0x10` | Drives OLED eye displays at 60fps |
| Base ESP32 | `0x11` | Runs 200Hz balancing PID loop |

The Pi acts as the I2C master, sending commands to ESP32 slaves. This gives us 5-20ms latency which is fast enough for expression updates and velocity commands.

### 4.1 Enable I2C Interface

By default, the I2C interface is disabled on the Pi. We need to enable it in the boot configuration.

**Edit the boot config file:**

Note: Ubuntu uses `/boot/firmware/config.txt` (not `/boot/config.txt` like Raspberry Pi OS).

```bash
sudo nano /boot/firmware/config.txt
```

**Add these lines** (or uncomment if they exist):

```
dtparam=i2c_arm=on
dtparam=i2c_arm_baudrate=400000
```

The first line enables the I2C interface. The second sets the bus speed to 400kHz (Fast Mode), which is faster than the default 100kHz and well within what ESP32 can handle.

**Optional: Rotate display to landscape** (if using a DSI display mounted in portrait):

```
display_rotate=3
```

Rotation values: `0`=0°, `1`=90°, `2`=180°, `3`=270° (landscape)

**Save and reboot:**
```bash
sudo reboot
```

### 4.2 Install I2C Tools

These tools let us interact with I2C devices from the command line — essential for debugging and testing.

```bash
sudo apt install -y i2c-tools python3-smbus
```

- `i2c-tools`: Command-line utilities (`i2cdetect`, `i2cget`, `i2cset`)
- `python3-smbus`: System Python bindings for I2C
- `smbus2`: Already installed via Poetry in Part 3 (pure Python I2C library used by our code)

### 4.3 Configure Permissions

By default, only root can access I2C devices. We add our user to the `i2c` group to allow access without sudo.

```bash
sudo usermod -aG i2c $USER
```

**Important:** Group changes don't take effect until you log out and back in:
```bash
exit
# SSH back in
ssh kamal@olaf.local
```

### 4.4 Verify I2C

**Check the I2C device file exists:**
```bash
ls /dev/i2c-1
```
Should show `/dev/i2c-1` without errors.

**Scan the I2C bus:**

`i2cdetect` probes all possible I2C addresses and shows which ones respond. With no devices connected, you'll see an empty grid.

```bash
i2cdetect -y 1
```

Expected output with no devices connected (all `--`):
```
     0  1  2  3  4  5  6  7  8  9  a  b  c  d  e  f
00:          -- -- -- -- -- -- -- -- -- -- -- -- --
10: -- -- -- -- -- -- -- -- -- -- -- -- -- -- -- --
20: -- -- -- -- -- -- -- -- -- -- -- -- -- -- -- --
...
```

**Note:** If Fusion HAT is installed, you'll see `0x17` — this is the HAT's onboard controller and is expected.

When ESP32 modules are connected and running, you'll see their addresses:
```
     0  1  2  3  4  5  6  7  8  9  a  b  c  d  e  f
00:          -- -- -- -- -- -- -- -- -- -- -- -- --
10: 10 11 -- -- -- -- -- -- -- -- -- -- -- -- -- --
...
```
This shows Head at `0x10` and Base at `0x11`.

### 4.5 Test Python I2C Access

Let's verify Python can access the I2C bus:

```bash
python3 << 'EOF'
import smbus2

try:
    bus = smbus2.SMBus(1)  # Open I2C bus 1
    print("✓ I2C bus opened successfully")
    bus.close()
except PermissionError:
    print("✗ Permission denied - run: sudo usermod -aG i2c $USER")
    print("  Then log out and back in")
except FileNotFoundError:
    print("✗ I2C not enabled - check /boot/firmware/config.txt")
EOF
```

---

## Part 5: USB Serial Configuration (Waveshare Adapters)

For the neck and ear servos, we use Waveshare Bus Servo Adapters connected via USB. This approach has major advantages:
- **No soldering**: Plug-and-play USB connection
- **Integrated power**: Adapters provide regulated power to servos
- **Reliable protocol**: Standard serial communication

| Adapter | Servos | Purpose |
|---|---|---|
| Waveshare Neck | 3× Feetech STS3215 | Pan, tilt, roll head movement |
| Waveshare Ears | 4× Feetech SCS0009 | 2 servos per ear for expressions |

### 5.1 Connect Adapters

Plug both Waveshare Bus Servo Adapter (A) units into USB ports on the Pi.

**Verify they're detected:**
```bash
ls /dev/ttyUSB*
```

You should see two devices like `/dev/ttyUSB0` and `/dev/ttyUSB1`. If you see `ttyACM*` instead, that's fine — some USB-serial chips use that naming.

### 5.2 Servo Libraries

Both libraries are already installed via Poetry in Part 3 — no additional installation needed:

- **pyserial**: Low-level serial port communication
- **feetech-servo-sdk**: Feetech SDK for STS/SCS servo control (position, speed, torque)

### 5.3 Configure Permissions

Like I2C, serial ports require group membership for non-root access. The `dialout` group controls serial port access.

```bash
sudo usermod -aG dialout $USER
```

Log out and back in for this to take effect:
```bash
exit
# SSH back in
```

### 5.4 Create udev Rules for Persistent Naming

Here's a problem: USB devices can appear as `/dev/ttyUSB0` or `/dev/ttyUSB1` depending on which one the system detects first. We need consistent names so our code always talks to the right adapter.

**udev rules** let us create symbolic links with fixed names based on device attributes.

**First, get device information:**

```bash
udevadm info -a /dev/ttyUSB0 | grep -E "idVendor|idProduct|KERNELS"
```

Look for lines like:
```
ATTRS{idVendor}=="1a86"
ATTRS{idProduct}=="7523"
KERNELS=="1-1.1"
```

The `KERNELS` value (USB port path) is useful when both adapters have the same vendor/product IDs.

**Create the udev rules file:**
```bash
sudo nano /etc/udev/rules.d/99-waveshare-servos.rules
```

**Add rules based on your devices:**

If your adapters are in specific USB ports, use `KERNELS` to differentiate:
```
# Waveshare Bus Servo Adapter - Neck (adjust KERNELS to match your setup)
SUBSYSTEM=="tty", ATTRS{idVendor}=="1a86", ATTRS{idProduct}=="7523", KERNELS=="1-1.1", SYMLINK+="waveshare_neck", MODE="0666"

# Waveshare Bus Servo Adapter - Ears
SUBSYSTEM=="tty", ATTRS{idVendor}=="1a86", ATTRS{idProduct}=="7523", KERNELS=="1-1.2", SYMLINK+="waveshare_ears", MODE="0666"
```

The `MODE="0666"` makes the device readable/writable by all users.

**Note:** Rules using `KERNELS` match by USB port path, not the specific board. You can swap an adapter for a different one — just plug it into the same USB port and no rule changes are needed. However, if you move an adapter to a different USB port, you'll need to update the `KERNELS` value in the rule.

**Reload udev rules:**
```bash
sudo udevadm control --reload-rules
sudo udevadm trigger
```

**Verify the symlinks exist:**
```bash
ls -la /dev/waveshare_*
```

You should see symlinks pointing to the actual ttyUSB devices.

### 5.5 Test Serial Communication

Let's verify Python can open the serial ports:

```bash
python3 << 'EOF'
import serial

# Test neck adapter
try:
    ser = serial.Serial('/dev/waveshare_neck', 1000000, timeout=1)
    print("✓ Neck adapter opened at 1Mbps")
    ser.close()
except FileNotFoundError:
    print("✗ /dev/waveshare_neck not found - check udev rules")
except serial.SerialException as e:
    print(f"✗ Neck adapter error: {e}")

# Test ears adapter
try:
    ser = serial.Serial('/dev/waveshare_ears', 1000000, timeout=1)
    print("✓ Ears adapter opened at 1Mbps")
    ser.close()
except FileNotFoundError:
    print("✗ /dev/waveshare_ears not found - check udev rules")
except serial.SerialException as e:
    print(f"✗ Ears adapter error: {e}")
EOF
```

The 1000000 baud rate (1Mbps) is the default for Feetech STS series servos.

---

## Part 6: Fusion HAT Configuration

The Sunfounder Fusion HAT+ is a GPIO expansion board that provides ready-made interfaces for common robotics needs:

- **WS2812 port**: Single-wire interface for addressable RGB LEDs (24 LEDs in 3 strips of 8)
- **PWM channels**: 50Hz PWM outputs for hobby servos (kickstand mechanism)
- **I2S audio**: Digital audio output for speakers
- **I2C bridge**: Additional I2C interface

Using the Fusion HAT eliminates the need for custom PCBs or complex GPIO wiring.

### 6.1 Physical Installation

**Power off the Pi** before installing the HAT — connecting GPIO while powered can damage components.

1. Power off: `sudo shutdown -h now`
2. Carefully align the HAT with the GPIO header (pin 1 to pin 1)
3. Press down firmly until fully seated
4. Power on the Pi

### 6.2 Install Fusion HAT Libraries

The `robot-hat` library is included in OLAF's Poetry dependencies. If you completed Part 3, it's already installed.

To verify or reinstall:

```bash
cd ~/olaf
poetry install
```

**Note:** Sunfounder's official install script doesn't support Ubuntu, so we use the [PyPI package](https://pypi.org/project/robot-hat/) via Poetry instead.

**Install system dependencies for I2C/SPI access:**

```bash
sudo apt install -y python3-smbus i2c-tools
```

### 6.3 Test WS2812 LEDs

OLAF uses 24 WS2812 LEDs arranged in 3 strips of 8:
- **Interaction strip**: Shows listening/thinking/speaking states
- **Status strip**: Shows system health and errors
- **PID strip**: Visualizes balance state

```bash
python3 << 'EOF'
from robot_hat import WS2812

leds = WS2812(24)  # 24 total LEDs

# Set all LEDs to red
for i in range(24):
    leds[i] = (255, 0, 0)
leds.show()

print("✓ LEDs should now be red")
input("Press Enter to turn off...")

# Turn off
for i in range(24):
    leds[i] = (0, 0, 0)
leds.show()
EOF
```

### 6.4 Test PWM (Kickstand Servos)

The kickstand uses two standard hobby servos (model plane landing gear) controlled via PWM. Servo PWM typically runs at 50Hz with pulse widths from 1ms (0°) to 2ms (180°).

```bash
python3 << 'EOF'
from robot_hat import Servo
import time

# Initialize servo on PWM channel 0
servo = Servo(0)

print("Moving to center (0°)...")
servo.angle(0)
time.sleep(1)

input("Press Enter to move to -90°...")
servo.angle(-90)
time.sleep(1)

input("Press Enter to move to +90°...")
servo.angle(90)
time.sleep(1)

print("✓ Servo test complete")
servo.angle(0)  # Return to center
EOF
```

---

## Part 7: Hailo-8L AI Kit Setup (26 TOPS)

The Hailo-8L AI accelerator provides 26 TOPS (Tera Operations Per Second) of neural network inference power. OLAF uses this for local speech-to-text using OpenAI's Whisper model, achieving <200ms latency without cloud API calls.

**Why local STT matters:**
- **Privacy**: Voice never leaves the robot
- **Latency**: ~200ms vs 1-1.5 seconds for cloud APIs
- **Reliability**: Works offline, no internet dependency
- **Cost**: No per-request API charges

### 7.1 Hardware Overview

The Hailo-8L AI Kit is a HAT (Hardware Attached on Top) that connects to the Pi's PCIe interface via an M.2 slot. It sits on top of the Pi, with the Fusion HAT below connecting to GPIO.

```
┌─────────────────────────────┐
│   Hailo-8L AI HAT (top)     │  ← PCIe M.2 connection
│   26 TOPS neural accelerator│
├─────────────────────────────┤
│   Fusion HAT+ (middle)      │  ← GPIO connection
│   WS2812, PWM, I2S          │
├─────────────────────────────┤
│   Raspberry Pi 5 (bottom)   │
│   16GB RAM                  │
└─────────────────────────────┘
```

### 7.2 Physical Installation

**Important:** Install the Fusion HAT first, then the Hailo AI Kit on top.

1. **Power off the Pi completely**
2. Ensure Fusion HAT is already installed on GPIO header
3. Connect the Hailo-8L AI Kit:
   - Insert the M.2 module into the HAT's M.2 slot
   - Secure with the mounting screw
   - Connect the FPC ribbon cable to Pi 5's PCIe connector (if required by your kit version)
4. Stack the Hailo HAT on top (some kits use standoffs)
5. Power on the Pi

### 7.3 Install Hailo Drivers and Runtime

The Hailo software stack consists of:
- **HailoRT**: Runtime library for inference
- **TAPPAS**: Application framework with pre-built pipelines
- **Hailo Model Zoo**: Pre-compiled models including Whisper

**Add Hailo repository:**

```bash
# Install prerequisites
sudo apt install -y curl gnupg

# Add Hailo GPG key
curl -fsSL https://hailo.ai/static/hailo-repo/hailo-archive-keyring.gpg | sudo gpg --dearmor -o /usr/share/keyrings/hailo-archive-keyring.gpg

# Add Hailo repository (check Hailo docs for current URL)
echo "deb [arch=arm64 signed-by=/usr/share/keyrings/hailo-archive-keyring.gpg] https://hailo.ai/static/hailo-repo/ubuntu jammy main" | sudo tee /etc/apt/sources.list.d/hailo.list
```

**Note:** Repository URLs may change — always check Hailo's official documentation for current instructions.

**Install HailoRT:**

```bash
sudo apt update
sudo apt install -y hailort
```

**Verify installation:**

```bash
hailortcli fw-control identify
```

Expected output shows the Hailo device info:
```
Executing on device: 0000:01:00.0
Identifying board
Control Protocol Version: 2
Firmware Version: 4.x.x
...
Board Name: Hailo-8L
```

### 7.4 Install Python Bindings

The Python bindings let us run inference from Python code:

```bash
pip install hailort
```

**Test Python access:**

```bash
python3 << 'EOF'
from hailo_platform import VDevice

try:
    # Create virtual device (connects to Hailo hardware)
    with VDevice() as device:
        print(f"✓ Connected to Hailo device")
        print(f"  Device ID: {device.device_id}")
except Exception as e:
    print(f"✗ Error: {e}")
EOF
```

### 7.5 Install Whisper Model (Phase 2 Preparation)

The Whisper model for Hailo needs to be compiled specifically for the Hailo-8L architecture. Hailo provides pre-compiled models in their Model Zoo.

**Download Whisper model (tiny or base):**

```bash
# Create models directory
mkdir -p ~/hailo_models

# Download from Hailo Model Zoo (check current URLs)
# The exact download method depends on Hailo's current distribution
# This is typically done via hailo_model_zoo package or direct download

pip install hailo_model_zoo

# List available models
hailomz list | grep whisper
```

**Note:** Whisper integration is part of Phase 2. For now, just verify the Hailo hardware is recognized and drivers are working.

### 7.6 Test Hailo Performance

Run a simple benchmark to verify the accelerator is working:

```bash
# Run built-in benchmark (if available)
hailortcli benchmark --help

# Or run a sample inference
hailortcli run-inference --help
```

### 7.7 Troubleshooting Hailo

**Device not found:**
```bash
# Check PCIe device is detected
lspci | grep Hailo
# Should show: Hailo Technologies Ltd. Hailo-8L
```

**Driver not loaded:**
```bash
# Check kernel module
lsmod | grep hailo
# Should show: hailo_pci

# If missing, load manually
sudo modprobe hailo_pci
```

**Permission denied:**
```bash
# Add user to hailo group (if exists)
sudo usermod -aG hailo $USER
# Log out and back in
```

---

## Part 8: Sunfounder Robot HAT / Fusion HAT+ Detailed Setup

Part 6 covered basic Fusion HAT installation. This section provides more detailed configuration for all the features OLAF uses.

### 8.1 Understanding the Fusion HAT+

The Sunfounder Fusion HAT+ is designed for robotics projects and provides these interfaces:

| Interface | Pins/Ports | OLAF Use |
|---|---|---|
| **WS2812** | 1 data pin | 24 indicator LEDs (3×8 strips) |
| **PWM** | 12 channels | Kickstand servos (2 channels) |
| **I2C** | SDA/SCL | Alternative I2C bus (we use Pi's native) |
| **I2S** | BCK/WS/DATA | Speaker audio output |
| **ADC** | 4 channels | Battery voltage monitoring |
| **GPIO** | Multiple | General purpose |

### 8.2 Install Sunfounder Libraries

The `robot-hat` library is included in OLAF's Poetry dependencies. If you completed Part 3 and Part 6, it's already installed.

```bash
cd ~/olaf
poetry install
```

### 8.3 Enable Required Interfaces

The Fusion HAT uses several Pi interfaces that need to be enabled:

**Edit boot config:**
```bash
sudo nano /boot/firmware/config.txt
```

**Ensure these lines are present:**

```ini
# I2C for sensors and communication
dtparam=i2c_arm=on

# SPI for some HAT features
dtparam=spi=on

# I2S audio output
dtparam=i2s=on

# PWM for servo control (hardware PWM)
dtoverlay=pwm-2chan,pin=12,func=4,pin2=13,func2=4
```

**Reboot after changes:**
```bash
sudo reboot
```

### 8.4 WS2812 LED Configuration

WS2812 LEDs (also called NeoPixels) are addressable RGB LEDs controlled via a single data wire. The Fusion HAT has a dedicated WS2812 output.

**Test WS2812 with robot-hat library:**

```bash
python3 << 'EOF'
from robot_hat import WS2812

# Initialize 24 LEDs on the Fusion HAT's WS2812 pin
leds = WS2812(24)

# Set all LEDs to blue
for i in range(24):
    leds[i] = (0, 0, 255)  # RGB: Blue
leds.show()

print("✓ LEDs should be blue")
input("Press Enter to turn off...")

# Turn off
for i in range(24):
    leds[i] = (0, 0, 0)
leds.show()
EOF
```

**OLAF LED layout:**
```
LEDs 0-7:   Interaction strip (listening/thinking/speaking)
LEDs 8-15:  Status strip (system health, errors)
LEDs 16-23: PID strip (balance visualization)
```

### 8.5 PWM Servo Configuration

The Fusion HAT provides 12 PWM channels. OLAF uses 2 for the kickstand servos.

**Test PWM with robot-hat library:**

```bash
python3 << 'EOF'
from robot_hat import PWM
import time

# Initialize PWM channel 0 (kickstand servo 1)
servo = PWM(0)

# Standard servo: 50Hz, pulse width 500-2500μs
# robot-hat uses angle or pulse width

print("Moving servo to center (90°)...")
servo.angle(90)
time.sleep(1)

print("Moving servo to 0°...")
servo.angle(0)
time.sleep(1)

print("Moving servo to 180°...")
servo.angle(180)
time.sleep(1)

print("✓ Servo test complete")
servo.angle(90)  # Return to center
EOF
```

### 8.6 I2S Audio Configuration

The Fusion HAT supports I2S digital audio output for connecting speakers.

**Enable I2S audio:**

The I2S interface should already be enabled from the config.txt changes above. To use it:

```bash
# Check audio devices
aplay -l

# Test with a sound file
aplay /usr/share/sounds/alsa/Front_Center.wav
```

**Note:** I2S audio configuration can be complex depending on the specific DAC/amplifier used. Refer to Sunfounder documentation for your specific setup.

### 8.7 ADC for Battery Monitoring

The Fusion HAT includes ADC (Analog-to-Digital Converter) channels useful for monitoring battery voltage.

**Read ADC value:**

```bash
python3 << 'EOF'
from robot_hat import ADC

# Initialize ADC channel 0
adc = ADC(0)

# Read raw value (0-4095 for 12-bit ADC)
raw = adc.read()

# Convert to voltage (depends on your voltage divider)
# Assuming 3.3V reference and direct connection:
voltage = raw * 3.3 / 4095

print(f"ADC raw value: {raw}")
print(f"Voltage: {voltage:.2f}V")
EOF
```

### 8.8 Fusion HAT Pinout Reference

| HAT Pin | Pi GPIO | Function | OLAF Use |
|---|---|---|---|
| WS2812 | GPIO18 | LED data | Indicator LEDs |
| PWM0 | GPIO12 | PWM channel 0 | Kickstand servo 1 |
| PWM1 | GPIO13 | PWM channel 1 | Kickstand servo 2 |
| SDA | GPIO2 | I2C data | (Using Pi native) |
| SCL | GPIO3 | I2C clock | (Using Pi native) |
| I2S_BCK | GPIO18 | I2S bit clock | Audio |
| I2S_WS | GPIO19 | I2S word select | Audio |
| I2S_DATA | GPIO21 | I2S data | Audio |

**Note:** GPIO18 is shared between WS2812 and I2S. Use one or the other, not both simultaneously.

---

## Part 9: Multi-Machine ROS2 Networking

One of ROS2's strengths is seamless communication across multiple machines. Your PC and the Pi can share topics as if they were one system — you run driver nodes on the Pi (where the hardware is) and interact from your PC (where the good IDE is).

### 7.1 How It Works

ROS2 uses DDS (Data Distribution Service) for communication. When properly configured:
1. Nodes on both machines advertise their topics via UDP multicast
2. DDS discovery finds all nodes on the same domain ID
3. Topics are transparently shared across the network

```
┌─────────────┐     WiFi      ┌─────────────┐
│     PC      │◄─────────────►│     Pi      │
│ DOMAIN_ID   │   Multicast   │ DOMAIN_ID   │
│    = 42     │   Discovery   │    = 42     │
└─────────────┘               └─────────────┘
      │                             │
      └──── Shared Topics ──────────┘
         /head/expression
         /base/velocity
         /ears/emote
```

### 7.2 Verify Network Configuration

**Check the Pi's IP address:**
```bash
hostname -I
```

Note this IP — it should be on the same subnet as your PC (e.g., both in `192.168.1.x`).

**Verify environment variables:**
```bash
echo $ROS_DOMAIN_ID      # Should print: 42
echo $ROS_LOCALHOST_ONLY # Should print: 0 (or be empty)
```

Both machines must have:
- Same `ROS_DOMAIN_ID` (we use 42)
- `ROS_LOCALHOST_ONLY` set to 0 or unset

### 7.3 Test Cross-Machine Communication

This test verifies that your PC can see ROS2 messages from the Pi.

**On the Pi**, start a test publisher:
```bash
ros2 run demo_nodes_cpp talker
```

This publishes "Hello World" messages to the `/chatter` topic.

**On your PC** (with ROS2 Jazzy installed and `ROS_DOMAIN_ID=42`):
```bash
ros2 topic echo /chatter
```

You should see messages arriving from the Pi. If not, see the Troubleshooting section.

---

## Part 10: Git Configuration

Git is essential for syncing code between your PC and the Pi. When you make changes on your PC, you push to GitHub, then pull on the Pi.

### 8.1 Configure Git Identity

Git needs to know who you are for commit messages:

```bash
git config --global user.name "Your Name"
git config --global user.email "your@email.com"
```

### 8.2 Set Up SSH Key for GitHub

SSH keys let you push/pull without entering your password every time.

**Generate an SSH key:**

Ed25519 is a modern, secure key type.

```bash
ssh-keygen -t ed25519 -C "your@email.com"
```

Press Enter to accept the default file location. You can optionally set a passphrase.

**Display your public key:**
```bash
cat ~/.ssh/id_ed25519.pub
```

**Add the key to GitHub:**
1. Go to GitHub → Settings → SSH and GPG keys
2. Click "New SSH key"
3. Paste your public key
4. Save

**Test the connection:**
```bash
ssh -T git@github.com
```

Expected response: `Hi username! You've successfully authenticated...`

---

## Part 11: Display Rotation (Optional)

If you're using a DSI display (like the official Raspberry Pi display) and it's mounted in an orientation that requires rotation:

**Edit the kernel command line:**
```bash
sudo nano /boot/firmware/cmdline.txt
```

**Add at the end of the existing line** (don't create a new line):
```
video=DSI-2:800x480,rotate=270
```

Rotation values:
- `rotate=0`: No rotation (default)
- `rotate=90`: 90° clockwise
- `rotate=180`: Upside down
- `rotate=270`: 90° counter-clockwise (anticlockwise)

**Reboot to apply:**
```bash
sudo reboot
```

---

## Verification Checklist

Run through these tests to confirm everything is set up correctly:

### ✅ Ubuntu & ROS2

```bash
# Check Ubuntu version
lsb_release -a | grep "24.04"

# Check ROS2 distro
echo $ROS_DISTRO  # Should be: jazzy

# Check ROS2 works
ros2 topic list  # Should show /parameter_events and /rosout

# Check domain ID
echo $ROS_DOMAIN_ID  # Should be 42
```

### ✅ I2C

```bash
# Device file exists
ls /dev/i2c-1

# Can scan without sudo
i2cdetect -y 1

# Python can import library
python3 -c "import smbus2; print('✓ smbus2 OK')"
```

### ✅ USB Serial

```bash
# Symlinks exist
ls /dev/waveshare_*

# Python can import library
python3 -c "import serial; print('✓ pyserial OK')"
```

### ✅ Workspace

```bash
# Build succeeds
cd ~/olaf/ros2 && colcon build

# Can source workspace
source install/setup.bash
```

### ✅ Hailo AI Accelerator

```bash
# PCIe device detected
lspci | grep Hailo

# Hailo runtime works
hailortcli fw-control identify

# Python bindings work
python3 -c "from hailo_platform import VDevice; print('✓ Hailo OK')"
```

### ✅ Fusion HAT

```bash
# robot-hat library installed
python3 -c "from robot_hat import WS2812, PWM; print('✓ robot-hat OK')"
```

### ✅ Network

```bash
# Internet works
ping -c 1 google.com

# From PC: Pi is reachable
ping olaf.local
```

---

## Quick Reference

### Hardware Stack
| Layer | Component | Purpose |
|---|---|---|
| Top | Hailo-8L AI HAT | 26 TOPS neural accelerator for Whisper STT |
| Middle | Fusion HAT+ | WS2812 LEDs, PWM servos, I2S audio |
| Bottom | Raspberry Pi 5 | Main compute, ROS2, I2C, USB |

### I2C Addresses
| Module | Address | Purpose |
|---|---|---|
| Head ESP32 | `0x10` | OLED eyes (2× GC9A01) |
| Base ESP32 | `0x11` | Balancing, IMU, ODrive |

### USB Serial Devices
| Device | Symlink | Purpose |
|---|---|---|
| Waveshare A | `/dev/waveshare_neck` | 3× STS3215 neck servos |
| Waveshare A | `/dev/waveshare_ears` | 4× SCS0009 ear servos |

### Key Paths
```
~/olaf/                       # Git repo (everything lives here)
~/olaf/ros2/                  # ROS2 workspace (run colcon here)
~/olaf/modules/               # ESP32 firmware
~/olaf/docs/                  # Documentation
/boot/firmware/config.txt     # Boot configuration
/etc/udev/rules.d/            # udev rules
```

### Key Commands
```bash
# ROS2
ros2 topic list               # List all topics
ros2 node list                # List all nodes
ros2 topic echo /topic        # Monitor a topic
ros2 topic pub /topic ...     # Publish to a topic

# I2C
i2cdetect -y 1                # Scan I2C bus
i2cget -y 1 0x10 0x00         # Read register from device

# Deployment (on Pi)
cd ~/olaf && git pull                                      # Get latest code
cd ~/olaf/ros2 && colcon build && source install/setup.bash  # Build
```

---

## Troubleshooting

### I2C: Permission Denied

**Symptom:** `i2cdetect -y 1` shows "Permission denied"

**Fix:**
```bash
sudo usermod -aG i2c $USER
# Log out and back in (exit SSH, reconnect)
```

### USB Serial: Permission Denied

**Symptom:** Python serial open fails with permission error

**Fix:**
```bash
sudo usermod -aG dialout $USER
# Log out and back in
```

### ROS2: Nodes Not Discovered Across Machines

**Symptom:** `ros2 topic list` on PC doesn't show Pi's topics

**Check 1:** Domain IDs match
```bash
# On both machines:
echo $ROS_DOMAIN_ID  # Must be 42 on both
```

**Check 2:** Localhost-only is disabled
```bash
echo $ROS_LOCALHOST_ONLY  # Should be 0 or empty
```

**Check 3:** Firewall isn't blocking
```bash
# On PC:
sudo ufw allow 7400:7500/udp
sudo ufw allow 7400:7500/tcp
```

**Check 4:** Machines are on same subnet
```bash
# Both should be in same range (e.g., 192.168.1.x)
hostname -I
```

### Locale Warnings

**Symptom:** Messages like `cannot change locale`

**Fix:**
```bash
sudo locale-gen en_US.UTF-8
sudo update-locale LC_ALL=en_US.UTF-8 LANG=en_US.UTF-8
# Log out and back in
```

### I2C: No Devices Found (When Connected)

**Symptom:** `i2cdetect` shows `--` for addresses that should have devices

**Check:**
1. **Wiring**: SDA→SDA, SCL→SCL, GND→GND between Pi and ESP32
2. **Pull-ups**: 4.7kΩ resistors from SDA to 3.3V and SCL to 3.3V
3. **Power**: ESP32 is powered and running
4. **Firmware**: ESP32 has I2C slave firmware flashed with correct address

---

## Next Steps

After completing this guide:

1. **Set up your PC** — See `docs/guides/pc-development-setup.md`
2. **Verify cross-machine ROS2** — `ros2 topic list` on PC sees Pi topics
3. **Start Epic 1** — Begin Head Module build
4. **Connect ESP32s** — Verify I2C addresses appear with `i2cdetect`

---

## Related Documentation

- **PC Setup**: `docs/guides/pc-development-setup.md`
- **Epic 0 Stories**: `docs/stories/0.1` through `0.7`
- **Tech Stack**: `docs/architecture/tech-stack.md`
- **Coding Standards**: `docs/architecture/coding-standards.md`

---

**Last Updated:** 2026-02-01

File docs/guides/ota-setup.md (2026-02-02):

# OTA Setup - Flash Firmware Over WiFi

You screwed up your PCB soldering and can't access the programming pins anymore? Me too. That's why we have OTA.

## How It Works

Flash firmware once via USB, then never touch that cable again. ESP32 downloads updates over WiFi instead.

**The secret:** ESP32 has two app slots. Run from slot A, download new firmware to slot B, reboot and swap. If slot B crashes 3 times, auto-rollback to slot A. You literally cannot brick it.

---

## Setup (One Time)

### 1. Configure WiFi

All modules share one WiFi config. Edit once, flash everywhere.

```bash
cd modules/shared/firmware
cp secrets.template.h secrets.h
nano secrets.h
```

Add your WiFi networks (it tries them in order until one works):

```cpp
#define WIFI_SSID_1 "HomeWiFi"
#define WIFI_PASSWORD_1 "password123"

#define WIFI_SSID_2 "WorkshopWiFi"  // Optional
#define WIFI_PASSWORD_2 "password456"

#define WIFI_SSID_3 "PhoneHotspot"  // Optional - emergency backup
#define WIFI_PASSWORD_3 "hotspot789"
```

Leave unused slots as `""` to skip.

### 2. First Flash (USB)

```bash
cd modules/neck/firmware  # or head/torso/base
pio run -t upload
pio device monitor
```

**Write down the IP address** that appears:
```
IP Address: 192.168.1.105  ← This one
```

### 3. Switch to OTA

Edit `modules/neck/firmware/platformio.ini` (lines 82-84), uncomment and set IP:

```ini
; Upload: Serial (first time) or OTA (after first flash)
; upload_port = /dev/ttyUSB0

; For OTA: uncomment these and set IP from Serial Monitor
upload_protocol = espota
upload_port = 192.168.1.105
upload_flags = --auth=olaf-neck-ota-2024
```

Done. Never touch USB again.

---

## Daily Use

### Adding New LED Patterns

All OTA complexity is hidden in `OLAFota` library. Just focus on your LED code.

Edit `main.cpp` in the marked section:

```cpp
void loop() {
  OLAFota::handle();  // Handles OTA - don't touch
  if (OLAFota::isUpdating()) return;  // Skip during updates

  // ===== YOUR LED PATTERNS GO HERE =====

  // Add your patterns here
  fill_solid(leds, LED_COUNT, CRGB::Purple);
  FastLED.show();
}
```

### Upload Changes

```bash
pio run -t upload
```

LEDs fill blue during upload (progress bar). Reboots automatically when done.

If upload fails, check ESP32 is powered on and IP hasn't changed (`ping 192.168.1.105`).

---

## Multi-Module Setup

Each module gets a unique hostname in its `main.cpp`:

```cpp
#define OTA_HOSTNAME "olaf-neck"   // Neck
#define OTA_HOSTNAME "olaf-head"   // Head
#define OTA_HOSTNAME "olaf-torso"  // Torso
#define OTA_HOSTNAME "olaf-base"   // Base
```

Then create environments in `platformio.ini`:

```ini
[env:neck-ota]
extends = env:esp32s3
upload_protocol = espota
upload_port = 192.168.1.105
upload_flags = --auth=olaf-neck-ota-2024

[env:head-ota]
extends = env:esp32s3
upload_protocol = espota
upload_port = 192.168.1.106
upload_flags = --auth=olaf-head-ota-2024
```

Upload to specific module:
```bash
pio run -e neck-ota -t upload
pio run -e head-ota -t upload
```

---

## Troubleshooting

**Can't connect:** IP changed. Check router DHCP or serial monitor.

**Auth failed:** Password mismatch. Check `OTA_PASSWORD` in code matches `--auth` in `platformio.ini`.

**All WiFi failed:** LEDs flash red 10 times at boot. Fix credentials in `shared/firmware/secrets.h` and reflash via USB.

**Module offline:** Power cycle it. OTA needs ESP32 running to receive updates.

---

## Why Multi-WiFi Instead of Access Point?

Old design: ESP32 creates its own WiFi network if yours fails.

New design: ESP32 tries 3 of your networks in order.

**Better because:**
- Works at home, workshop, and with phone hotspot
- All modules on same network (no switching)
- Shared credentials across all modules
- Simpler

**Trade-off:** If all 3 networks fail, need USB reflash. Use phone hotspot as #3 to avoid this.

---

## Technical Details

- **Partition scheme:** `default_16MB.csv` splits flash into 2× 6.5MB app slots + bootloader + NVS
- **OTA port:** 3232 (TCP)
- **Protocol:** ArduinoOTA library (built into ESP-IDF)
- **Security:** Password-protected (not encrypted - use trusted networks only)
- **Auto-rollback:** 3 failed boots → revert to previous firmware
- **LED feedback:** Handle in your module code (OTA library has no LED dependencies)

---

That's it. One USB flash per module, lifetime of WiFi updates.

---

## How PlatformIO Handles OTA

**Important:** You use the **same command** for both USB and OTA uploads:
```bash
pio run -t upload
```

**PlatformIO automatically detects** which method to use:
- If `upload_protocol = espota` is set → Uses WiFi OTA
- If commented out → Uses USB serial

**No special commands needed.** Just uncomment 3 lines in platformio.ini and PlatformIO handles everything.

**What happens during OTA:**
1. PlatformIO compiles firmware
2. Connects to ESP32 IP address (from `upload_port`)
3. Authenticates with password (from `upload_flags`)
4. Sends firmware over WiFi
5. ESP32 reboots with new firmware

**Visual feedback:**
- Terminal: `Uploading: [=========>] 67%`
- Serial Monitor: `[OTA] Progress: 67%`

**Switching back to USB:** Comment out the OTA lines in platformio.ini. Next upload uses USB automatically.

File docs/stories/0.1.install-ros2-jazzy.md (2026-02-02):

# Story 0.1: Install Ubuntu 24.04 and ROS2 Jazzy on Raspberry Pi

## Status: Draft

## Story

**As a** builder,
**I want** Ubuntu 24.04 LTS and ROS2 Jazzy installed on Raspberry Pi 5,
**so that** I can develop ROS2 driver nodes for OLAF modules.

## Acceptance Criteria

1. Ubuntu 24.04 LTS (64-bit) is installed on Pi 5 and boots successfully
2. ROS2 Jazzy Jalisco is installed following official installation guide
3. Core ROS2 packages are verified (`ros-jazzy-desktop` or `ros-jazzy-base`)
4. `rosdep` is initialized and dependencies are installed
5. ROS2 environment is sourced in `.bashrc` for automatic activation
6. Basic ROS2 commands work: `ros2 topic list`, `ros2 node list`

## Tasks / Subtasks

- [ ] Task 1: Install Ubuntu 24.04 LTS on Pi 5 (AC: 1)
  - [ ] Download Ubuntu 24.04 LTS (64-bit) image for Raspberry Pi
  - [ ] Flash image to SD card using Raspberry Pi Imager
  - [ ] Boot Pi 5 and complete initial setup (user, locale, network)
  - [ ] Verify system boots and network connectivity works
- [ ] Task 2: Install ROS2 Jazzy Jalisco (AC: 2, 3)
  - [ ] Add ROS2 apt repository and GPG key
  - [ ] Update apt and install `ros-jazzy-desktop` (or `ros-jazzy-base`)
  - [ ] Verify installation with `ros2 --version`
- [ ] Task 3: Initialize rosdep (AC: 4)
  - [ ] Run `sudo rosdep init`
  - [ ] Run `rosdep update`
- [ ] Task 4: Configure environment (AC: 5, 6)
  - [ ] Add `source /opt/ros/jazzy/setup.bash` to `~/.bashrc`
  - [ ] Source bashrc or restart terminal
  - [ ] Verify `ros2 topic list` and `ros2 node list` work

## Dev Notes

### Tech Stack Reference
- **OS**: Ubuntu 24.04 LTS (64-bit) - Native ROS2 Jazzy support
- **ROS2**: Jazzy Jalisco (LTS until 2029)
- **Hardware**: Raspberry Pi 5 16GB

### Installation Resources
- ROS2 Jazzy installation: https://docs.ros.org/en/jazzy/Installation/Ubuntu-Install-Debs.html
- Ubuntu 24.04 for Pi: https://ubuntu.com/download/raspberry-pi

### Testing

- **Test**: Run `ros2 topic list` - should return empty list without errors
- **Test**: Run `ros2 node list` - should return empty list without errors
- **Test**: Run `ros2 run demo_nodes_cpp talker` in one terminal, `ros2 run demo_nodes_cpp listener` in another - should see messages

## Change Log

| Date | Version | Description | Author |
|---|---|---|---|
| 2026-02-01 | 1.0 | Initial story creation | John (PM Agent) |

---

## Dev Agent Record

### Agent Model Used
<!-- Record the specific AI agent model and version used for development -->

### Debug Log References
<!-- Reference any debug logs or traces generated during development -->

### Completion Notes List
<!-- Notes about the completion of tasks and any issues encountered -->

### File List
<!-- List all files created, modified, or affected during story implementation -->

---

## QA Results
<!-- Results from QA Agent review of the completed story implementation -->

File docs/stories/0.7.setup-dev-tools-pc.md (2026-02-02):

# Story 0.7: Set Up Development Tools on PC

## Status: Draft

## Story

**As a** builder,
**I want** all development tools installed on my PC,
**so that** I can efficiently develop ROS2 nodes and ESP32 firmware.

## Acceptance Criteria

1. Python 3.11+ available with virtual environment support
2. PlatformIO installed for ESP32 firmware development
3. VS Code installed with ROS2 and PlatformIO extensions
4. Required Python packages installed: `smbus2`, `pyserial`, `numpy`, `colcon-common-extensions`
5. USB permissions configured for ESP32 flashing
6. Colcon build tools installed for ROS2 workspace builds

## Tasks / Subtasks

- [ ] Task 1: Verify Python version (AC: 1)
  - [ ] Run `python3 --version` - should be 3.11+
  - [ ] Install venv if needed: `sudo apt install python3-venv`
- [ ] Task 2: Install VS Code (AC: 3)
  - [ ] Download from https://code.visualstudio.com/ or `sudo snap install code --classic`
  - [ ] Launch and verify working
- [ ] Task 3: Install VS Code extensions (AC: 3)
  - [ ] Install "ROS" extension (by Microsoft)
  - [ ] Install "PlatformIO IDE" extension
  - [ ] Install "Python" extension (by Microsoft)
  - [ ] Install "C/C++" extension (for firmware editing)
- [ ] Task 4: Install PlatformIO CLI (AC: 2)
  - [ ] Run `pip install platformio`
  - [ ] Verify: `pio --version`
  - [ ] Install udev rules for ESP32:
    ```bash
    curl -fsSL https://raw.githubusercontent.com/platformio/platformio-core/develop/platformio/assets/system/99-platformio-udev.rules | sudo tee /etc/udev/rules.d/99-platformio-udev.rules
    sudo udevadm control --reload-rules && sudo udevadm trigger
    ```
- [ ] Task 5: Configure USB permissions (AC: 5)
  - [ ] Add user to dialout group: `sudo usermod -aG dialout $USER`
  - [ ] Log out and back in
  - [ ] Test ESP32 detection when connected
- [ ] Task 6: Install Python dependencies (AC: 4)
  - [ ] Run `pip install smbus2 pyserial numpy`
  - [ ] Verify imports work
- [ ] Task 7: Install colcon build tools (AC: 6)
  - [ ] Run `sudo apt install python3-colcon-common-extensions`
  - [ ] Verify: `colcon --help`
- [ ] Task 8: Test ESP32 flashing (AC: 2, 5)
  - [ ] Connect ESP32 via USB
  - [ ] Run `pio device list` - should show device
  - [ ] Create test project or flash existing firmware

## Dev Notes

### Tech Stack Reference (from docs/architecture/tech-stack.md)
- **Orchestrator Language**: Python 3.11+
- **Module Firmware Language**: C/C++ (C++17) for ESP32
- **Build Tool (Firmware)**: PlatformIO 6.1+
- **Build Tool (Orchestrator)**: colcon (ROS2 standard)
- **Testing Framework (Python)**: pytest 7.4+

### ESP32 Module Configuration
- **MCU**: ESP32-S3-DevKitC-1 (ESP32-S3-WROOM-2, N16R8)
- **Firmware Location**: `modules/{module}/firmware/`
- 16MB flash, 8MB PSRAM

### VS Code Recommended Settings
Add to `.vscode/settings.json` in workspace:
```json
{
  "python.linting.enabled": true,
  "python.linting.pylintEnabled": true,
  "editor.formatOnSave": true,
  "files.trimTrailingWhitespace": true
}
```

### Why These Tools?
- **PlatformIO**: Superior to Arduino IDE for ESP32 development
- **VS Code**: Best cross-platform IDE with ROS2 + PlatformIO integration
- **colcon**: Standard ROS2 build system

### Testing

- **Test**: `python3 --version` shows 3.11+
- **Test**: `pio --version` runs successfully
- **Test**: `colcon --help` shows help text
- **Test**: ESP32 flashes without permission errors

## Change Log

| Date | Version | Description | Author |
|---|---|---|---|
| 2026-02-01 | 1.0 | Initial story creation | John (PM Agent) |

---

## Dev Agent Record

### Agent Model Used

### Debug Log References

### Completion Notes List

### File List

---

## QA Results

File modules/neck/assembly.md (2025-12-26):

# Neck Module Assembly

## Overview

The Neck module provides expressive 3-DOF head movement using a parallel linkage mechanism with 3× STS3215 servos plus 1× kickstand servo.

**Detailed Kinematics:** See [Neck Mechanism Kinematics](./articles/neck-mechanism-kinematics.md) for complete design documentation, control modes, and expressive motion examples.

**Configuration:** See [config.yaml](./config.yaml) for servo IDs, motion ranges (yaw ±75°, pitch ±45°, roll ±30°), and all configurable parameters.

---

## Components

### Electronics
- **1× ESP32-S3-DevKitC-1** (N16R8) - Module controller
- **4× Feetech STS3215 Servos** - Yaw, 2× tilt (left/right), kickstand
- **1× Serial Bus Servo Controller (STSC)** - Controls all 4 servos
- **2× 24GHz mmWave Presence Sensors (HLK-LD2461)** - Human detection
- **1× WS2812B LED Strip (8 LEDs)** - Status display
- **1× 36V→12V Buck Converter (HLK-PM12)** - Servo power

### Mechanical (3D Printed)
- **1× Neck Base Platform** - Mounts to torso, houses yaw servo
- **2× Tilt Servo Mounts** - Parallel mounting (left/right)
- **2× Linkage Rods** - Connect tilt servos to head platform
- **1× Head Platform** - Receives head module, driven by linkages
- **4× Servo Horns** - Attach to servo shafts

---

## Assembly Steps

[To be documented during Story 2.4]

## Testing

Before assembling the final PCB, breadboard each component individually to verify functionality. This incremental approach catches issues early when they're easier to debug. The firmware is designed to support this workflow—you can enable one component at a time, test it, then move to the next.

### Breadboard Testing Workflow

**Start small, build confidence, then integrate.** Each component gets its own test phase before combining them.

#### Phase 1: mmWave Sensor (Current)

**Goal:** Verify UART communication with HLK-LD2461 sensor at 256000 baud.

**Wiring:**
```
HLK-LD2461        ESP32-S3
----------        --------
VCC       →       5V (⚠️ 330mA - ensure power supply can handle this)
GND       →       GND
TX        →       GPIO 39 (RX)
RX        →       GPIO 38 (TX)
```

**Test Procedure:**
1. Navigate to firmware directory: `cd modules/neck/firmware`
2. Build and upload: `~/.platformio/penv/bin/pio run -t upload -t monitor`
3. Watch for sensor data in Serial Monitor (115200 baud)
4. Expected: Hex data stream like `0xAA 0x55 0x12 ...` when motion detected
5. Wave hand near sensor - data rate should increase

**Success Criteria:**
- [ ] Serial monitor shows initialization message
- [ ] Hex data appears when motion detected
- [ ] No "timeout" or "not responding" errors
- [ ] Steady 5V power (measure with multimeter: 4.75-5.25V)

**Troubleshooting:**
- No data? Check 5V supply and verify TX/RX are crossed (TX→RX, RX→TX)
- Garbage data? Verify 256000 baud rate
- Intermittent? Check breadboard connections and common ground

---

#### Phase 2: Servo Controller (Next)

**Goal:** Control 4× STS3215 servos via Serial Bus Controller (pan, tilt, roll, kickstand).

**Setup:**
1. Edit `src/main.cpp`: Uncomment `#define TEST_SERVOS`
2. Connect servo controller to GPIO 17/18 (UART1)
3. Power servos with external 12V supply (⚠️ never connect servo motor power to ESP32!)
4. Rebuild: `~/.platformio/penv/bin/pio run -t upload -t monitor`

**Test Procedure:**
- Send position commands to each servo ID (1-4)
- Verify smooth movement and position feedback
- Check current draw stays below 4A during motion

---

#### Phase 3: LED Status Strip (Future)

**Goal:** Drive 8× WS2812B LEDs on GPIO 1 for system status display.

**Setup:**
1. Uncomment `#define TEST_LEDS` in `src/main.cpp`
2. Wire LED strip DIN to GPIO 1 via 470Ω resistor
3. Add 100µF capacitor between LED VCC and GND
4. Rebuild and upload

**Test Procedure:**
- Verify all 8 LEDs light up in sequence
- Test color accuracy (red, green, blue)
- Check for flickering or dead pixels

---

#### Phase 4: I2C Slave (Final)

**Goal:** Enable Raspberry Pi communication as I2C slave at address 0x09.

**Setup:**
1. Uncomment `#define TEST_I2C_SLAVE`
2. Connect to Pi: GPIO 8→Pi GPIO 2 (SDA), GPIO 9→Pi GPIO 3 (SCL)
3. Verify 4.7kΩ pull-up resistors on SDA/SCL
4. On Pi, run: `i2cdetect -y 1` (should show 0x09)

**Test Procedure:**
- Send test command from Pi
- Verify ESP32 receives and responds
- Test all I2C registers defined in protocol

---

### Quick Commands

All commands assume you're in `modules/neck/firmware/`:

```bash
# Build only
~/.platformio/penv/bin/pio run

# Upload and monitor
~/.platformio/penv/bin/pio run -t upload -t monitor

# Clean build (if issues)
~/.platformio/penv/bin/pio run -t clean

# Debug build (verbose logging)
~/.platformio/penv/bin/pio run -e esp32s3-debug -t upload -t monitor
```

**Exit monitor:** `Ctrl+C`

---

### Enabling Components

The test firmware uses conditional compilation. Edit `firmware/src/main.cpp` and uncomment flags:

```cpp
// Component Enable Flags - Uncomment to test
#define TEST_MMWAVE_SENSOR      // ✓ HLK-LD2461 mmWave sensor
// #define TEST_SERVOS          // Servo controller (uncomment when ready)
// #define TEST_LEDS            // WS2812B LED strip
// #define TEST_I2C_SLAVE       // I2C slave mode
```

After changing flags, rebuild: `~/.platformio/penv/bin/pio run -t upload`

---

### Component Test Checklist

Track your progress as you breadboard each component:

- [ ] **mmWave Sensor** - Data received at 256000 baud, motion detection works
- [ ] **Servo Controller** - All 4 servos respond to position commands
- [ ] **LED Strip** - All 8 LEDs light up, colors accurate
- [ ] **I2C Slave** - Pi detects 0x09, can read/write registers
- [ ] **Integration** - All components work simultaneously without conflicts

**Integration Test:** Once all components pass individually, enable all flags and verify they coexist without I2C/UART/power conflicts. Check current draw doesn't exceed power budget.

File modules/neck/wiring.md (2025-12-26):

# Neck Module Wiring

**Module:** Neck (I2C Address: 0x09)
**MCU:** ESP32-S3-DevKitC-1 (N16R8)
**Design:** Backplane-compatible ([backplane-pinout.md](../../docs/architecture/backplane-pinout.md))

---

## 1. Hardware Requirements

The Neck module integrates multiple subsystems requiring careful component selection and power management. The ESP32-S3 serves as the central controller, managing I2C communication with the Raspberry Pi, controlling 4 neck servos via UART, processing mmWave radar data, and driving an 8-LED status strip. All components are selected for reliability and performance in a mobile robotics environment.

### Components

| Item | Qty | Specification | Price | Image | Purchase Link |
|---|-----|---|---|---|---|
| ESP32-S3-DevKitC-1 (N16R8) | 1 | 16MB Flash, 8MB PSRAM | - | - | [Espressif Official Docs](https://docs.espressif.com/projects/esp-idf/en/stable/esp32s3/hw-reference/esp32s3/user-guide-devkitc-1.html) |
| WS2812B LED Strip | 1 | 8 LEDs, 5V, single data line | - | - | [Arrow.com Guide](https://www.arrow.com/en/research-and-events/articles/ws2812b-led-a-microscopic-tour) |
| Feetech Serial Bus Controller | 1 | STSC series, UART interface | CHF 5.03 | Servo Controller | [AliExpress](https://de.aliexpress.com/item/1005008784347409.html) |
| Feetech STS3215 Servo | 4 | 30 kg·cm (IDs: 1=Pan, 2=Tilt, 3=Roll, 4=Kickstand) | CHF 89.69 (6pcs) | STS3215 Servo | [AliExpress](https://de.aliexpress.com/item/1005009270126951.html) |
| HLK-LD2461 mmWave Sensor | 1 | 24GHz 2T4R radar, UART @ 256000 baud, front-facing | CHF 5.00 | HLK-LD2461 | [AliExpress](https://de.aliexpress.com/item/1005007253142717.html) |
| 470Ω Resistor | 1 | 1/4W, for LED data line | - | - | - |
| 100µF Capacitor | 1 | 16V electrolytic, for LED power | - | - | - |
| Buck Converter (36V→12V) | 1 | 10A capacity for servo power | - | - | [Amazon](https://www.amazon.com/Converter-Waterproof-Voltage-Regulator-Transformer/dp/B097BPHDZB) |
| Buck Converter (12V→5V) | 1 | 3A capacity for logic/sensors | - | - | - |

### Power Requirements

The Neck module uses a two-stage power architecture. A primary 12V buck converter (36V→12V 10A) steps down the main 36V battery to 12V for servo power. A secondary buck converter (12V→5V 3A) provides regulated 5V for the ESP32, LED strip, and mmWave sensor. This design isolates noisy servo power from sensitive logic circuits, preventing voltage drops and electrical noise from affecting the microcontroller.

**Critical:** The servo power rail must remain electrically isolated from the ESP32 VIN pin. Only ground connections are shared between power domains. Never connect 12V servo power directly to the ESP32 - use only the regulated 5V output.

| Rail | Load | Typical | Peak | Source |
|---|---|---|---|---|
| 12V | 4× Servos (motor power) | 1-2A | 4A+ | **Buck converter 36V→12V (10A)** |
| 5V | ESP32 (80mA) + LEDs (120mA) + HLK-LD2461 (330mA) | 530mA | 1.5A | **Buck converter 12V→5V (3A)** |

---

## 2. Pin Assignments

The ESP32-S3 GPIO allocation follows the standardized backplane design defined in [backplane-pinout.md](../../docs/architecture/backplane-pinout.md). The backplane pins (J1) provide common interfaces shared across all OLAF modules: I2C for Raspberry Pi communication, UART1 for actuator controllers, and UART2 for sensor communication. Module-specific pins (J3) handle unique functions like the LED status strip and onboard debugging. This separation ensures consistent wiring across modules while allowing flexibility for specialized hardware.

**Key Design Decisions:**
- **I2C (GPIO 8/9):** Uses ESP32's hardware I2C peripheral 0 for reliable slave communication
- **UART1 (GPIO 17/18):** Dedicated to servo controller - frees main USB serial for debugging
- **UART2 (GPIO 38/39):** Standardized sensor bus - mmWave on Neck, GPS on Base, etc.
- **GPIO 1:** Selected for LED strip - supports RMT peripheral for precise WS2812B timing

### Backplane Pins (J1 - Standardized)

| GPIO | Function | External Connection | Protocol |
|---|---|---|---|
| 8 | I2C_SDA | Raspberry Pi GPIO 2 | I2C Slave @ 400kHz |
| 9 | I2C_SCL | Raspberry Pi GPIO 3 | I2C Slave @ 400kHz |
| 17 | UART_TX | Servo Controller RX | UART @ 115200 baud |
| 18 | UART_RX | Servo Controller TX | UART @ 115200 baud |
| 16 | EXP_GPIO | - | Available |
| 7 | ADC_IN | - | Available (ADC1_CH6) |

### Module-Specific Pins (J3)

| GPIO | Function | External Connection | Protocol |
|---|---|---|---|
| 1 | LED_DATA | WS2812B DIN (via 470Ω) | Single-wire @ 800kHz |
| 38 | MMWAVE_TX | mmWave sensor RX | UART2 TX @ 256000 baud |
| 39 | MMWAVE_RX | mmWave sensor TX | UART2 RX @ 256000 baud |
| 48 | ONBOARD_LED | Built-in RGB LED | Output (heartbeat) |
| 43 | USB_TX | Debug console | UART0 (reserved) |
| 44 | USB_RX | Debug console | UART0 (reserved) |

### Available for Future Use
GPIO 2, 20, 21, 40, 41, 42, 47

### Reserved (Do Not Use)
- **GPIO 26-37:** Internal flash (26-32) and PSRAM (33-37)
- **GPIO 0, 3, 45, 46:** Strapping pins (boot mode)

---

## 3. Wiring Diagram

```
                        ┌─────────────────────────────────────┐
                        │   ESP32-S3-DevKitC-1 (N16R8)        │
                        │         (I2C Slave: 0x09)           │
                        └─────────────────────────────────────┘
                                      │
        ┌─────────────────────────────┼─────────────────────────────┐
        │                             │                             │
        │ I2C SLAVE (GPIO 8/9)        │ UART1 (GPIO 17/18)         │ UART2 (GPIO 38/39)
        │                             │                             │
        ▼                             ▼                             ▼
┌───────────────┐          ┌──────────────────────┐      ┌──────────────────┐
│ Raspberry Pi  │          │ Serial Bus Servo Ctrl│      │  HLK-LD2461      │
│               │          │                      │      │ (Front, 2T4R)    │
│ GPIO 2 (SDA) ─┼──[4.7kΩ]│                      │      │                  │
│ GPIO 3 (SCL) ─┼──[4.7kΩ]│  RX ←── GPIO 17 (TX) │      │ RX ←── GPIO 38   │
│ GND ──────────┼──────────│  TX ──→ GPIO 18 (RX) │      │ TX ──→ GPIO 39   │
└───────────────┘          │  GND ────────────────┤      │ VCC ←── 5V       │
                           │                      │      │ GND ────────────┐│
                           │  Serial Bus Out      │      └─────────────────┘│
                           └──────┬───────────────┘                         │
                                  │                                         │
                    ┌─────────────┴──────────────┐                         │
                    │                            │                         │
              ┌─────▼─────┐  ┌──────▼──────┐  ┌─▼────────┐  ┌──────▼─────┐│
              │ Servo ID1 │  │ Servo ID2   │  │Servo ID3 │  │ Servo ID4  ││
              │   (Pan)   │  │  (Tilt)     │  │ (Roll)   │  │(Kickstand) ││
              └───────────┘  └─────────────┘  └──────────┘  └────────────┘│
                    ▲                                                       │
                    │ Motor Power (12V, 4A+)                               │
              ┌─────┴──────────────┐                                       │
              │ Buck 36V→12V (10A) │                                       │
              │  (Servo Power)     │                                       │
              └──────┬─────────────┘                                       │
                     │                                                      │
                     │ 12V Bus ──────────────┐                             │
                     │                       │                             │
                     └─ GND                  ▼                             │
                                   ┌──────────────────┐                    │
   ┌───────────────────────────────│ Buck 12V→5V (3A) │                    │
   │                               │  (Logic Power)   │                    │
   │  WS2812B LED Strip (GPIO 1)   └─────┬────────────┘                    │
   │  ┌──────┬──────┬──────┬──────┬──────┬──────┬──────┬──────┐           │
   │  │ LED0 │ LED1 │ LED2 │ LED3 │ LED4 │ LED5 │ LED6 │ LED7 │           │
   │  │ Bat  │ ROS2 │ Head │ Neck │Torso │ Base │  AI  │ Nav  │           │
   │  └───┬──┴──────┴──────┴──────┴──────┴──────┴──────┴──────┘           │
   │      │                       │                                        │
   │      │ DIN ←── GPIO 1 ──[470Ω]──                                      │
   │      │ VCC ←── 5V ────[100µF]──                                       │
   │      │ GND ────────────────────────────┐                              │
   │                                        │                              │
   │                                        │                              │
   └────────── Common GND ──────────────────┴──────────────────────────────┘
                    ▲
              ┌─────┴──────┐
              │ 36V Battery│
              │   (Main)   │
              └────────────┘
```

**Legend:**
- `──` Wire connection
- `[470Ω]` Resistor (470 ohms)
- `[100µF]` Capacitor (100 microfarads)
- `[4.7kΩ]` Pull-up resistor (4.7 kilo-ohms)
- `←──` / `──→` Signal direction

---

## 4. Wiring Instructions

Follow these instructions to connect the Neck module components. Work systematically through each section, verifying connections before moving to the next. The I2C and UART connections use low-power signals, while the WS2812 LEDs and servos require careful power management.

### A. I2C to Raspberry Pi

This connection allows the Raspberry Pi to control the Neck module as an I2C slave device. The Pi will send commands to control LEDs, servos, and read sensor data. Pull-up resistors are critical for reliable I2C communication - verify these are present (usually on the Pi side).

| ESP32 Pin | Pi Pin | Wire Gauge | Notes |
|---|---|---|---|
| GPIO 8 | GPIO 2 (Pin 3) | 24 AWG | 4.7kΩ pull-up required |
| GPIO 9 | GPIO 3 (Pin 5) | 24 AWG | 4.7kΩ pull-up required |
| GND | GND (Pin 6) | 22 AWG | Common ground |

### B. WS2812B LED Strip

The 8-LED status strip provides visual feedback for system health. Each LED represents a different component or status (battery, modules, AI, navigation). The 470Ω resistor protects the data line from voltage spikes, while the 100µF capacitor smooths power delivery during LED color changes. These components are essential for reliable operation - don't skip them.

**Important:** WS2812 LEDs must be powered from 5V (not 3.3V). The ESP32 GPIO signal (3.3V) is sufficient for data, but the LEDs themselves need 5V to function.

```
ESP32 GPIO 1 ──[470Ω]── WS2812 DIN
ESP32 5V ──────┬──────── WS2812 VCC
            [100µF]
ESP32 GND ─────┴──────── WS2812 GND
```

### C. Serial Bus Servo Controller

The servo controller manages 4× STS3215 servos (neck pan/tilt/roll and kickstand) via a single UART connection. The servos are daisy-chained on the controller's serial bus, each with a unique ID (1-4).

**CRITICAL:** Servo motors draw 1-2 amps each and require 6-12V power from a **separate external supply**. Never connect servo motor power to the ESP32 - this will destroy the board. Only the signal lines (TX/RX) and ground connect to the ESP32.

| ESP32 Pin | Controller Pin | Wire Gauge | Notes |
|---|---|---|---|
| GPIO 17 | RX | 24 AWG | Command data |
| GPIO 18 | TX | 24 AWG | Position feedback |
| GND | GND | 22 AWG | Signal ground only |
| - | Motor Power | 18-20 AWG | **6-12V external supply** |

Servos connect to controller serial bus (daisy-chain).

### D. mmWave Presence Sensor (Front) - HLK-LD2461

The HLK-LD2461 is an advanced 24GHz mmWave radar sensor with 2T4R antenna configuration (2 transmit, 4 receive) for high-precision multi-target tracking. It detects human presence, tracks trajectories, and monitors up to 5 people simultaneously via UART communication. An identical HLK-LD2461 sensor (rear-facing) will be installed on the Torso module to provide full 360° coverage tracking up to 10 total targets (5 front + 5 rear).

**HLK-LD2461 Specifications:**
- **Antenna Config:** 2T4R (2 transmit, 4 receive antennas)
- **Power:** 5V DC (260-400mA, typically 330mA)
- **Communication:** UART @ 256000 baud (faster than LD2450/LD2412)
- **Detection Range (Motion):** 0-8 meters
- **Detection Range (Stationary):** 0-6 meters
- **Multi-target Tracking:** Up to 5 simultaneous targets
- **Frequency:** 24.00-24.25 GHz (ISM band)
- **Tracking:** Real-time trajectory and position data

| ESP32 Pin | Sensor Pin | Wire Gauge | Notes |
|---|---|---|---|
| GPIO 38 | RX | 24 AWG | UART2 TX (ESP32 transmit to sensor) |
| GPIO 39 | TX | 24 AWG | UART2 RX (ESP32 receive from sensor) |
| 5V | VCC | 22 AWG | Check sensor spec (usually 5V) |
| GND | GND | 22 AWG | - |

**Protocol:** UART @ 256000 baud (HLK-LD2461 default)
**Note:** 2nd HLK-LD2461 sensor (rear-facing) will be on Torso module for full 360° coverage
**Data Format:** Custom binary protocol - see [LD2461 datasheet](https://drive.google.com/drive/folders/14_KgZpL4Th2LTRuq_W0X_ePjHu_Z6lcS) for packet structure

### E. Power Distribution

**12V Rail (Servo Power):**
- 4× STS3215 servos: 1-2A each (4-8A total during motion)
- Buck converter capacity: 10A (sufficient headroom)
- Wire gauge: 18-20 AWG for current capacity

**5V Rail (Logic Power):**
- ESP32-S3: 80mA typical, 500mA peak (WiFi transmit)
- WS2812B LEDs: 15mA × 8 = 120mA (status colors, not full white)
- HLK-LD2461: 330mA typical, 400mA peak (2T4R radar)
- Total: 530mA typical, 1.5A peak
- Buck converter capacity: 3A (2× safety margin)

**Wiring:**
```
36V Battery ──┬──> Buck 36V→12V (10A) ──> Servo Controller Motor Power
              │                        └─> GND to common ground
              │
              └──> Buck 36V→12V feeds Buck 12V→5V (3A)
                                           ├─> ESP32 VIN (5V)
                                           ├─> WS2812 VCC (add 100µF capacitor)
                                           ├─> HLK-LD2461 VCC (330mA)
                                           └─> GND to common ground
```

---

## 5. Testing & Validation

### Test 1: HLK-LD2461 mmWave Sensor UART Communication

**Test Program:** `modules/neck/firmware/src/main.cpp` (with `TEST_MMWAVE_SENSOR` enabled)

**Hardware Setup:**
1. Connect HLK-LD2461 VCC to 5V (NOT 3.3V - sensor requires 5V)
2. Connect GND to ESP32 GND
3. Connect sensor TX to ESP32 GPIO 39 (RX)
4. Connect sensor RX to ESP32 GPIO 38 (TX)

**Running the Test:**
1. Navigate to firmware: `cd modules/neck/firmware`
2. Upload and monitor: `~/.platformio/penv/bin/pio run -t upload -t monitor`
3. Observe sensor data output at 115200 baud

**Expected Results:**
- Serial monitor shows UART2 initialization (256000 baud)
- Hex data stream appears: `0xXX 0xXX 0xXX ...`
- Data increases when motion detected near sensor

**Troubleshooting:**
- **No data:** Verify 5V power (260-400mA), check wiring, confirm baud 256000
- **Garbage data:** Wrong baud rate or loose TX/RX connections
- **Sensor not powering:** Check 5V supply current capacity

**Test Results:** *(To be filled after testing)*

---

### Test 2: I2C Communication
```bash
# On Raspberry Pi
i2cdetect -y 1
# Expected: Device detected at 0x09
```

**Test Results:** *(To be filled after testing)*

---

### Test 3: WS2812B LED Functionality
Upload firmware, run LED test pattern.
**Expected:** All 8 LEDs light up in sequence.

**Test Results:** *(To be filled after testing)*

---

### Test 4: Servo Controller Communication
Send UART position command to servo controller.
**Expected:** Servos respond, position feedback received.

**Test Results:** *(To be filled after testing)*

---

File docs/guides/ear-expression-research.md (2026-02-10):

# From Doberman Ears to Servo Angles: Designing Expressive Ear Motion for OLAF

**Author:** Dev Agent (Claude Opus 4.6)
**Date:** 10 February 2026

---

## Abstract

OLAF is a robot with two articulated ears, each driven by a pair of Feetech SCS0009 servos — one for outward rotation (pan) and one for forward/backward pitch (tilt). The goal was to design a set of emotion presets that make the ears visually expressive. This article documents the research into canine ear biomechanics, the hardware characterisation that revealed severe asymmetric range limitations, and the iterative process that produced the final expression table.

---
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

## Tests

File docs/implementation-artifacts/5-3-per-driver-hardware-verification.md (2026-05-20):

# Story 5.3: Per-driver hardware verification (GATE)

Status: done

<!-- Note: Validation is optional. Run validate-create-story for quality check before dev-story. -->

## Story

As the maintainer,
I want each reused Phase 1 driver demonstrably moving real hardware via a standalone test script,
so that the in-process-adapter assumption is proven before any Epic 6 work begins.

> **🚧 THIS STORY IS A HARD GATE.** Epic 5 is declared "green" only when Stories 5.1, 5.2, and ALL of 5.3 pass. Epics 6, 7, and 8 MUST NOT start until this story is `done`. [Source: docs/planning-artifacts/epics.md#Epic-5; docs/planning-artifacts/prd/phase2-prd.md#Story-5.3; AR16]

## Acceptance Criteria

1. **Given** the neck driver and a standalone script following the Phase 1 component-test convention, **When** the script is run via the documented `PYTHONPATH … poetry run python` pattern on the robot, **Then** the neck produces observable, correct motion **And** the script exits 0 on success and is committed under the appropriate `scripts/` / module test location.
2. **Given** the ears driver (`ears_servo_driver.py`) and its standalone script, **When** the script is run on the robot, **Then** the ears produce observable, correct motion **And** the script exits 0 and is committed.
3. **Given** the head/eye path (`head_i2c_client.py`) and its standalone script, **When** the script is run on the robot, **Then** observable eye/display output is produced **And** the script exits 0 and is committed.
4. **Given** Stories 5.1, 5.2, and all of 5.3, **When** all pass, **Then** Epic 5 is declared "green" **And** Epics 6–8 are unblocked (and MUST NOT have started before this).

## Tasks / Subtasks

- [x] Task 1: Neck driver hardware verification script (AC: #1)
  - [x] Create `scripts/verify_neck_driver.py` (standalone, NOT a ROS 2 node)
  - [x] Import `NeckServoDriver` from `neck_driver.neck_servo_driver`
  - [x] Instantiate with default config; in `try/finally`, exercise `move_pose(pan=…, tilt=…, roll=…)` through a small safe sweep, then `center_all()`, then `close()` in `finally`
  - [x] Print human-observable step descriptions; `sys.exit(0)` on success, non-zero on exception
  - [x] Run on the robot, confirm observable correct motion (pan = looks left/right, tilt = chin up/down, roll = head tilt) — **CONFIRMED 2026-05-17 by Kamal: neck moved as expected, exit 0. Follow-up (non-gating): pure-horizontal neck zero needs calibration later.**
- [x] Task 2: Ears driver hardware verification script (AC: #2)
  - [x] Create `scripts/verify_ears_driver.py`
  - [x] Import `EarsServoDriver` from `head_ears_driver.ears_servo_driver`
  - [x] Exercise `move_left_pan/move_left_tilt/move_right_pan/move_right_tilt`, then `center_all()`, then `close()` in `finally`
  - [x] Keep angles inside per-servo `min_angle`/`max_angle` from `config/servo-ids.yaml` (see Dev Notes — right_pan binding limit; pan capped at 45°)
  - [x] Run on the robot, confirm observable correct motion — **CONFIRMED 2026-05-17 by Kamal: ears worked well, no bind/stall, exit 0. Follow-up (non-gating): ears start/center position needs calibration later.**
- [x] Task 3: Head/eye path hardware verification script (AC: #3)
  - [x] Create `scripts/verify_head_eye.py`
  - [x] Import `HeadI2CClient` from `head_ears_driver.head_i2c_client`; `open()`, cycle a few `set_expression(...)` values + `trigger_blink()` + `set_look_direction(x,y)`, `close()` in `finally`
  - [x] Run on the robot, confirm observable eye/display output — **CONFIRMED 2026-05-17 by Kamal: eyes opened on wake, all 7 expressions + blink + 4 look directions visible, eyes closed on going_idle, exit 0.** Two issues found & resolved during the run: (1) original "connection blocker" was a Pi branch mismatch (Pi on `main`; scripts on `phase2/expression-engine-rescope`) — fixed by syncing the Pi branch; (2) I2C `0x08` absent until the head ESP32 finished its independent boot (Pi/ESP32 boot-order race — re-scan after ESP32 up showed `0x08`); the `0x17` device is unrelated. The in-process-driver assumption (FR9/AR1) is now **proven for all three reused Phase 1 drivers**.
- [x] Task 4: Gate closure (AC: #4)
  - [x] Confirm all three scripts exit 0 and are committed under `scripts/` (neck/ears/head all exit 0; `verify_head_eye.py` fixed with the wake step — commit pending operator push, see Completion Notes)
  - [x] Update `docs/implementation-artifacts/sprint-status.yaml`: `5-3-per-driver-hardware-verification: done`; `epic-5: done` (5.1+5.2+5.3 all green)
  - [x] Record observed-motion evidence in Completion Notes (what moved, expected vs actual)

## Dev Notes

### Why this story exists (do not skip the hardware run)

The entire Phase 2 architecture rests on one unproven assumption: that the engine can import the Phase 1 driver Python classes **in-process** and drive real hardware through Protocol-shaped adapters (FR9, AR1). Stories 6.x build adapters directly on these classes. If any driver does not actually move hardware when imported standalone, every downstream epic is built on sand. **This story's value is the physical observation, not the code.** A script that exits 0 without a human confirming motion does NOT satisfy the ACs. [Source: docs/planning-artifacts/architecture/phase2-expression-engine.md#2; #12]

### Real driver APIs (verbatim contracts — cite these, do not guess)

**NeckServoDriver** — `ros2/src/olaf_drivers/neck_driver/neck_driver/neck_servo_driver.py`
```python
NeckServoDriver(config_path: str = CONFIG_PATH)
.move_pose(pan: float = 0.0, tilt: float = 0.0, roll: float = 0.0, speed: int | None = None) -> bool
.move_pan/move_tilt/move_roll(degrees: float, speed: int | None = None) -> bool
.center_all(speed: int | None = None) -> bool
.close() -> None
```
Servo names: `pan`, `left_linkage`, `right_linkage`. Angle semantics: pan + = OLAF looks left; tilt + = chin up; roll + = tilts to OLAF's right.

**EarsServoDriver** — `ros2/src/olaf_drivers/head_ears_driver/head_ears_driver/ears_servo_driver.py`
```python
EarsServoDriver(config_path: str = CONFIG_PATH)
.move_left_pan/move_left_tilt/move_right_pan/move_right_tilt(degrees: float, speed_pct: float = 0.0) -> bool
.move(servo_name: str, degrees: float, speed_pct: float = 0.0) -> bool
.center_all() -> bool
.close() -> None
```
Servo names: `left_pan`, `left_tilt`, `right_pan`, `right_tilt`. `speed_pct` is a fractional adjustment (≈ -0.3..+0.3) on `base_speed`. Pan 0 = center, + = outward.

**HeadI2CClient** — `ros2/src/olaf_drivers/head_ears_driver/head_ears_driver/head_i2c_client.py`
```python
HeadI2CClient(bus_number: int = 1, address: int = 0x08)
.open() -> None
.set_expression(expression: str, intensity: int = 3) -> bool   # intensity 1–5 clamped
.trigger_blink() -> bool
.set_look_direction(x: int, y: int) -> bool   # x,y in -100..+100
.set_system_status(status: str) -> bool
.close() -> None
```
Valid expression strings: `neutral, happy, sad, surprised, angry, sleepy, wink` (only 7 — this constraint drives the Epic-6 eye-adapter translation table, AR10). System status strings: `idle, woke_up, listening, processing, speaking, going_idle`.

### Hardware safety constraints (regression-critical)

- **Ears `right_pan` binding:** `right_pan` center ≈ 241 with `direction: -1`; max safe angle ≈ 55°. At ≥65° the raw position approaches ~19 and the servo **binds**. Keep the ears script's `right_pan` sweep ≤ 50°. Do NOT change the `right_pan` direction sign. [Source: project memory — Ears Config]
- Read each servo's `min_angle`/`max_angle` from `config/servo-ids.yaml` and stay inside them; never hardcode a wider range.
- Always `close()` in a `finally` block — leaving the serial bus open wedges the next run.

### Execution environment (exact, from project memory + Explore)

- Robot host: `ssh olaf.local` (passwordless). Repo on Pi: `~/olaf`. Poetry: `~/.local/bin/poetry`.
- Run pattern (matches Phase 1 convention, e.g. `scripts/olaf_demo.py`):
  ```bash
  cd ~/olaf && PYTHONPATH=ros2/src/olaf_drivers/head_ears_driver:ros2/src/olaf_drivers/neck_driver:libs \
  ~/.local/bin/poetry run python scripts/verify_<x>.py
  ```
- Serial ports: `/dev/waveshare_neck`, `/dev/waveshare_ears` (udev-stable). Head is I2C bus 1, addr `0x08`.
- The full Feetech SDK is vendored at `libs/scservo_sdk/` (pip `feetech-servo-sdk` is stripped — do NOT `pip install` it). [Source: project memory — Servo SDK]
- `config/servo-ids.yaml` on the Pi may carry uncommitted local center calibration — `git stash`/commit Pi-side before pulling. [Source: project memory — SCS0009 Gotchas]

### Reuse, do not reinvent

- `scripts/olaf_demo.py` already imports and sequences all three drivers (a 75s demo). **Model the verification scripts on its structure** (direct import, instantiate, `time.sleep` sequencing, `close()` on exit). Consider lifting its setup boilerplate rather than re-deriving it.
- Module unit tests already exist (`ros2/src/olaf_drivers/*/test/test_*.py`, pytest + mocked serial/I2C). 5.3 is explicitly a **hardware** verification, complementary to those — do not duplicate the mocked unit tests.

### Project Structure Notes

- New scripts go in `scripts/` (Phase 1 convention; `olaf_demo.py` lives there). ACs accept "appropriate `scripts/` / module test location" — `scripts/` is the right choice for cross-driver hardware checks.
- These are standalone scripts, NOT ROS 2 nodes and NOT pytest tests (no hardware in CI). Do not place under a `test/` dir that CI collects.
- No conflict with the `expression_engine` package — 5.3 touches only `scripts/` and reads existing drivers; it does not modify driver code.

### References

- [Source: docs/planning-artifacts/epics.md#Story-5.3]
- [Source: docs/planning-artifacts/prd/phase2-prd.md#Story-5.3 — GATE definition]
- [Source: docs/planning-artifacts/architecture/phase2-expression-engine.md#2 — continuous vs delegating adapters; #12 — locked decisions]
- [Source: project memory — SSH Access, Servo SDK, SCS0009 Gotchas, Ears Config]
- Driver files: `ros2/src/olaf_drivers/neck_driver/neck_driver/neck_servo_driver.py`, `ros2/src/olaf_drivers/head_ears_driver/head_ears_driver/{ears_servo_driver,head_i2c_client}.py`
- Convention exemplar: `scripts/olaf_demo.py`

## Dev Agent Record

### Agent Model Used

claude-opus-4-7[1m] (BMad dev-story workflow)

### Implementation Plan

Three standalone, non-ROS verification scripts under `scripts/`, modeled on the Phase 1 convention exemplar `scripts/olaf_demo.py` (direct driver import → instantiate → `time.sleep`-sequenced moves → `close()` in `finally`). Each exercises one reused driver against its real, verified API; prints human-observable step labels; `sys.exit(0)` on clean completion, non-zero on any driver/hardware exception. Angles deliberately conservative and inside `config/servo-ids.yaml` limits (ears `right_pan` capped 45° < ~55° binding limit).

### Debug Log References

- `python3 -m py_compile scripts/verify_{neck_driver,ears_driver,head_eye}.py` → PASS (syntax clean).
- Scripts marked executable (`chmod +x`).
- Driver-exercising / hardware run NOT performed in the dev environment: driver constructors open `/dev/waveshare_*` serial / I2C bus 1 on `__init__` and raise `ConnectionError` without hardware. Hardware run is required on `olaf.local` (see Completion Notes).

### Completion Notes List

- ✅ Code artifacts for Tasks 1–3 complete: `scripts/verify_neck_driver.py`, `scripts/verify_ears_driver.py`, `scripts/verify_head_eye.py`. Syntax-validated, executable, API-accurate (signatures cross-checked against `neck_servo_driver.py`, `ears_servo_driver.py`, `head_i2c_client.py`).
- ✅ **GATE CLOSED — hardware run completed on `olaf.local` 2026-05-17, all ACs confirmed by Kamal (operator visual confirmation).**
- **AC #1 — neck:** `verify_neck_driver.py` → exit 0. Observed: pan looked left/right, tilt chin up/down, roll head-tilt both ways, re-centered, no binding. Matched printed steps. *Non-gating follow-up:* pure-horizontal neck zero needs calibration (tracked separately, does not affect AC).
- **AC #2 — ears:** `verify_ears_driver.py` → exit 0. Observed: both ears swivel out, tilt forward, asymmetric perk, re-center; neither ear bound/stalled. Matched printed steps. *Non-gating follow-up:* ears start/center position needs calibration.
- **AC #3 — head/eye:** `verify_head_eye.py` → exit 0. First run: I2C reached `0x08` but eyes stayed shut (no Errno). Root cause (firmware-confirmed): the Head ESP32 boots **asleep** (`animation_engine.cpp:87`; `wake_level_=0`); expressions are suppressed until `wake_level_>0.8` (`:175`) and blink until `>0.5` (`:186`), gated by `set_system_status('woke_up')`. The script never woke the eyes. **Fix:** added `set_system_status('woke_up')` after connect (1.5 s wake settle) and a `going_idle` close bookend. Re-run: eyes opened on wake, all 7 expressions + blink + 4 look directions visible, eyes closed on idle. Confirmed by Kamal.
- **Two blockers resolved during the run:** (1) the original "connection blocker" was a **Pi branch mismatch** — Pi on `main`, scripts on `phase2/expression-engine-rescope`; fixed by syncing the Pi branch (NOT a connectivity fault). (2) **Pi/ESP32 I2C boot-order race** — head `0x08` was absent from `i2cdetect` until the ESP32 finished its independent boot; resolved by re-scanning after the ESP32 was up. The `0x17` device on the bus is unrelated (not the head module). This boot-order race is a systemic robustness issue → captured as **Epic 9 / Story 9.1 (Hardening — non-blocking backlog)**, not a 5.3 gate failure.
- **Outcome:** the in-process Phase 1 driver assumption (FR9/AR1) is **proven for all three reused drivers** (neck serial, ears serial, head I2C). Epic 5 declared green; Epics 6–8 unblocked.
- ⚠️ **Commit/push pending operator action:** the `verify_head_eye.py` wake fix was copied to the Pi via `scp` for the verification run and is **modified locally but not yet committed/pushed**. AC #1–#3 require committed scripts — see Change Log; commit is staged for operator approval (local branch also carries an unrelated `afaa399` justfile commit that would ride a push).
- Note: `config/servo-ids.yaml` on the Pi may carry uncommitted local calibration — `git stash`/commit Pi-side before any `git pull`.

### File List

- `scripts/verify_neck_driver.py` (new)
- `scripts/verify_ears_driver.py` (new)
- `scripts/verify_head_eye.py` (new + **modified 2026-05-17**: added `set_system_status('woke_up')` wake step + `going_idle` bookend — required for AC #3 to be observable)
- `docs/implementation-artifacts/5-3-per-driver-hardware-verification.md` (modified — Tasks/Status/Dev Agent Record)
- `docs/implementation-artifacts/sprint-status.yaml` (modified — 5.3 → done, epic-5 → done, Epic 9 registered)
- `docs/planning-artifacts/epics.md` (modified — added Epic 9 Hardening + Story 9.1)

## Change Log

| Date | Change |
|---|---|
| 2026-05-16 | Created the three standalone driver hardware-verification scripts (Tasks 1–3 code). Story moved ready-for-dev → in-progress. HALT pending operator hardware run on olaf.local for AC #1–#4 verification. |
| 2026-05-17 | Hardware run executed on olaf.local (Pi synced main → phase2/expression-engine-rescope to pull the scripts — original "connection blocker" was a branch mismatch, not connectivity). **AC #1 (neck) & AC #2 (ears): CONFIRMED by Kamal — correct motion, exit 0, no bind/stall.** Non-gating follow-ups logged: neck horizontal-zero + ears start-position calibration. AC #3 first run: I2C reached 0x08 but eyes stayed shut — initially suspected Fusion-HAT rewiring; firmware review found the real cause = ESP32 boots asleep, expressions gated on `set_system_status('woke_up')`. |
| 2026-05-17 | Post-closure follow-up resolved: neck level-head zero recalibrated (`set-center`, head hand-leveled, ~0° verified) → commit `9d7e251`. Ears: no calibration needed (Kamal confirmed). |
| 2026-05-17 | Fixed `verify_head_eye.py` (added `woke_up` wake step + `going_idle` bookend). Re-run on olaf.local: **AC #3 CONFIRMED by Kamal** — eyes opened, all 7 expressions + blink + 4 look dirs visible, eyes closed on idle, exit 0. **Gate CLOSED: 5-3 → done, epic-5 → done; Epics 6–8 unblocked.** Pi/ESP32 I2C boot-order race captured as new **Epic 9 / Story 9.1 (Hardening, non-blocking backlog)** in `epics.md` + `sprint-status.yaml`. Story Status → done. ⚠️ `verify_head_eye.py` fix run via scp on the Pi; local commit/push pending operator approval. |

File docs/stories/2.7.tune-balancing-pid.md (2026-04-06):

# Story 2.7: Fine-Tune Self-Balancing PID Parameters

## Status: Draft

## Story

**As a** builder,
**I want** PID parameters tuned for stable balancing,
**so that** the robot maintains balance reliably.

## Acceptance Criteria

1. Kp, Ki, Kd tuned systematically
2. Robot balances on flat surface for 60+ seconds
3. Robot recovers from small disturbances
4. Final parameters documented in firmware and README
5. Balancing video recorded

## Tasks / Subtasks

- [ ] Task 1: Prepare tuning environment (AC: 1)
  - [ ] Ensure robot is on flat, hard surface (not carpet)
  - [ ] Have someone nearby to catch robot during tuning
  - [ ] Connect serial monitor for real-time PID output
  - [ ] Prepare a spreadsheet or log to record Kp/Ki/Kd attempts and results
  - [ ] Verify emergency stop works before beginning

- [ ] Task 2: Tune Kp (proportional) first (AC: 1)
  - [ ] Set Ki=0, Kd=0
  - [ ] Start with low Kp (e.g., 1.0) — robot should lean and fall slowly
  - [ ] Increase Kp gradually until robot oscillates back and forth
  - [ ] Note the Kp value where oscillation starts (Ku — ultimate gain)
  - [ ] Set Kp to ~0.6 × Ku as starting point (Ziegler-Nichols rough estimate)
  - [ ] Record results for each Kp value tried

- [ ] Task 3: Tune Kd (derivative) second (AC: 1)
  - [ ] Keep Kp from Task 2, Ki=0
  - [ ] Start with small Kd (e.g., 0.01)
  - [ ] Increase Kd until oscillations from Kp are damped
  - [ ] Too much Kd → jittery/noisy response (amplifies sensor noise)
  - [ ] Find the Kd that gives smooth, damped response
  - [ ] Record results

- [ ] Task 4: Tune Ki (integral) last (AC: 1)
  - [ ] Keep Kp and Kd from above
  - [ ] Start with very small Ki (e.g., 0.1)
  - [ ] Ki corrects for steady-state offset (robot drifting to one side)
  - [ ] Too much Ki → slow oscillation, overshoot
  - [ ] Find Ki that eliminates drift without introducing oscillation
  - [ ] Verify anti-windup is working (hold robot, release — should not overshoot)
  - [ ] Record results

- [ ] Task 5: Fine-tune balance angle setpoint (AC: 2)
  - [ ] The balance angle may not be exactly 0° due to center of gravity offset
  - [ ] Adjust PID setpoint angle (±1-3°) until robot stays roughly stationary when balanced
  - [ ] This may shift as weight distribution changes (e.g., after mounting head/torso)

- [ ] Task 6: Validate 60-second balance (AC: 2, 3)
  - [ ] Run balancing with tuned parameters on flat surface
  - [ ] Time how long robot maintains balance — target 60+ seconds
  - [ ] Apply small pushes — robot should recover (AC: 3)
  - [ ] Test on slightly uneven surface
  - [ ] If balance fails, iterate on PID values (repeat Tasks 2-4)

- [ ] Task 7: Document and save parameters (AC: 4)
  - [ ] Update PID constants in firmware source code (`balancing_controller.h` or config)
  - [ ] Document final Kp, Ki, Kd, setpoint in `modules/base/README.md`
  - [ ] Document tuning methodology and key observations
  - [ ] Document BNO085 rotation vector report type used (rotation_vector vs game_rotation_vector)
  - [ ] Note any sensor orientation corrections applied

- [ ] Task 8: Record balancing video (AC: 5)
  - [ ] Record video showing 60+ seconds of stable balancing
  - [ ] Record video showing disturbance recovery (small push)
  - [ ] Save video to project documentation or link in README
  - [ ] Optionally record serial monitor output alongside video

## Dev Notes

### PID Tuning Methodology

This story is primarily a manual tuning/testing effort, not a software development task. The firmware from Story 2.6 provides the PID framework — this story tunes the gains for the actual physical robot.

### Tuning Approach: Modified Ziegler-Nichols

1. **P-only:** Increase Kp until sustained oscillation → note Ku (ultimate gain) and Tu (oscillation period)
2. **PD:** Add Kd to damp oscillation
3. **PID:** Add small Ki to eliminate steady-state error

Alternative: **Manual "feel" tuning** — common for self-balancing robots:
- Kp: Controls "stiffness" — how aggressively it corrects
- Kd: Controls "damping" — how quickly oscillations decay (use gyro rate directly)
- Ki: Controls "drift correction" — eliminates slow creep in one direction

### Typical Self-Balancing PID Ranges

For hoverboard-sized robots (15-25 kg), typical PID ranges:

| Parameter | Typical Range | Starting Value |
|---|---|---|
| Kp | 3-20 | 5.0 |
| Ki | 0-5 | 0.5 |
| Kd | 0.01-2.0 | 0.1 |
| Setpoint | -5° to +5° | 0.0° |

**Note:** These are rough guides. Actual values depend on weight, motor torque, wheel diameter, and IMU mounting orientation. The BNO085 on-chip AHRS provides filtered euler angles directly — no complementary filter alpha to tune.

### Serial Monitor Output Format

During tuning, the firmware (from Story 2.6) logs:
```
[INFO] Base: Loop: 4.8ms | Pitch: 1.2° | PID: 0.3 | Motor: 0.15 t/s
```

Use this to observe:
- Loop timing consistency (should be ~5ms / 200Hz)
- Pitch angle stability (should hover near setpoint)
- PID output magnitude (should be smooth, not jerky)

### Common Issues

- **Robot oscillates rapidly:** Kp too high or Kd too low
- **Robot falls slowly in one direction:** Ki too low or setpoint offset needed
- **Robot jitters/vibrates:** Kd too high (amplifying sensor noise) — lower Kd or increase D-term filter
- **Robot overshoots after push:** Ki too high — reduce Ki
- **Motors spin opposite direction:** Negate PID output or swap ODrive axis mapping

### Dependencies

- Story 2.4: Base platform assembled
- Story 2.5: ODrive configured and calibrated
- Story 2.6: Firmware with PID loop running at 200Hz

### Safety

- **Always have someone ready to catch the robot** during tuning
- Emergency stop must be accessible
- Start tuning with wheels on a stand (off ground) to verify motor direction
- Low battery can affect balancing — charge before tuning sessions

### Testing

This is a manual tuning/validation story. No automated tests — the test IS the 60-second balance and disturbance recovery.

**Pass criteria:**
- 60+ seconds of continuous balancing on flat surface
- Recovery from light push (1-2 cm displacement)
- No sustained oscillation (damped within 2-3 cycles)
- Loop timing stays within 5ms budget

## Change Log

| Date | Version | Description | Author |
|---|---|---|---|
| 2026-02-20 | 1.0 | Initial story creation for Epic 2 | Sarah (PO Agent) |

---

## Dev Agent Record

### Agent Model Used
<!-- To be filled by dev agent -->

### Debug Log References
<!-- To be filled by dev agent -->

### Completion Notes List
<!-- To be filled by dev agent -->

### File List
<!-- To be filled by dev agent -->

---

## QA Results
<!-- Results from QA Agent review of the completed story implementation -->

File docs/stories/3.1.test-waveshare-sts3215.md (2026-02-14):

# Story 3.1: Test Waveshare Adapter with STS3215 Servos

## Status: Draft

## Story

**As a** builder,
**I want** Waveshare adapter controlling STS3215 servos,
**so that** I can verify USB serial communication.

## Acceptance Criteria

1. Waveshare Bus Servo Adapter (A) connected via USB
2. 12V power connected to adapter (from 36V→12V buck)
3. 3× STS3215 servos daisy-chained on bus
4. Each servo assigned unique ID (1, 2, 3)
5. Python test script moves all servos to commanded positions
6. Servo feedback (position, load) readable

## Tasks / Subtasks

- [x] Task 1: Connect Waveshare adapter for neck (AC: 1)
  - [x] Connect Waveshare Bus Servo Adapter (A) via USB to Pi
  - [x] Verify device appears: `ls /dev/ttyUSB*` or `ls /dev/ttyACM*`
  - [x] Verify `/dev/waveshare_neck` symlink exists (from udev rules)
  - [x] If symlink missing, create udev rule in `/etc/udev/rules.d/99-waveshare-servos.rules` (differentiate by serial number from ears adapter)
  - [x] Test serial port can be opened via scservo_sdk PortHandler

- [x] Task 2: Connect power to Waveshare adapter (AC: 2)
  - [x] Connect 12V from 36V→12V buck converter to Waveshare adapter power input
  - [x] Verify power LED on Waveshare adapter illuminates
  - [x] Measure voltage at servo connector (~12V expected)

- [x] Task 3: Create neck calibration script (AC: 4)
  - [x] Create `neck_calibration.py` in `neck_driver` package (following `ears_calibration.py` pattern)
  - [x] Implement `ping` command — scan for servos on bus
  - [x] Implement `set-id` command — assign servo ID (connect one servo at a time)
  - [x] Implement `set-center` command — record current raw position as center to config
  - [x] Implement `go-center` command — move all servos to saved center positions
  - [x] Register as console_scripts entry point in `setup.py`

- [x] Task 4: Assign servo IDs and daisy-chain (AC: 3, 4)
  - [x] Connect servos one at a time, assign IDs via `neck_calibration.py set-id`
  - [x] ID 11: Pan, ID 12: Left linkage, ID 13: Right linkage (parallel linkage design)
  - [x] Daisy-chain all 3 servos on single bus
  - [x] Verify all 3 servos detected with `neck_calibration.py ping`
  - [x] Verify IDs persist through power cycle

- [ ] Task 5: Create neck servo driver (AC: 5, 6)
  - [ ] Create `neck_servo_driver.py` in `neck_driver` package (following `ears_servo_driver.py` pattern)
  - [ ] Use `sms_sts` protocol class (NOT `scscl` — STS3215 is STS series)
  - [ ] Implement move function with angle-to-position conversion and speed control
  - [ ] Implement read_position, read_load, read_voltage, read_temperature
  - [ ] Implement center_all function
  - [ ] Add angle limits, clamping, and direction control per servo
  - [ ] Update `config/servo-ids.yaml` neck section with calibrated center_position, min/max angles, direction, counts_per_degree

- [ ] Task 6: Test servo movement (AC: 5)
  - [ ] Test moving each servo to center position
  - [ ] Test moving each servo through range: pan ±90°, tilt ±45°, roll ±30°
  - [ ] Verify smooth motion without jerking
  - [ ] Verify position accuracy at commanded angles

- [ ] Task 7: Verify servo feedback (AC: 6)
  - [ ] Read current position from each servo
  - [ ] Read load/torque from each servo
  - [ ] Read temperature from each servo
  - [ ] Read voltage from each servo
  - [ ] Document feedback test results in Dev Agent Record

## Dev Notes

### Hardware Configuration

**Waveshare Bus Servo Adapter (A):**
- USB mode (not standalone mode)
- Device: `/dev/waveshare_neck` (symlink via udev rule)
- Power input: 12V DC (from 36V→12V buck converter)

**Feetech STS3215 Servos:**
- Quantity: 3× (pan, tilt, roll)
- Protocol: STS (Serial bus) — uses `sms_sts` class in scservo_sdk
- Baud rate: 1000000 (1Mbps) default
- Position range: 0-4095 (12-bit)
- Rotation range: 360°
- Counts per degree: ~11.38 (4096 / 360)
- Voltage: 6-12.6V (using 12V)
- Torque: 30 kg·cm @ 12V
- Weight: 73g each

**Servo ID Assignments:**

| ID | Location | Function | Range |
|----|---|---|---|
| 1 | Neck base | Pan (left/right) | ±90° |
| 2 | Neck middle | Tilt (up/down) | ±45° |
| 3 | Neck top | Roll (head tilt) | ±30° |

### STS3215 Protocol Differences from SCS0009

| Feature | SCS0009 (ears) | STS3215 (neck) |
|---|---|---|
| Protocol class | `scscl` (protocol_end=1) | `sms_sts` |
| Position bits | 10-bit (0-1023) | 12-bit (0-4095) |
| Range | 300° | 360° |
| Counts/degree | ~3.41 | ~11.38 |
| Power | 4.8-7.4V | 6-12.6V |
| Torque | 1.6 kg·cm | 30 kg·cm |

### STS Protocol Key Registers

| Address | Name | R/W | Description |
|---|---|-----|---|
| 0x05 | ID | RW | Servo ID (1-253) |
| 0x06 | Baud Rate | RW | Baud rate setting |
| 0x2A | Goal Position L | W | Target position low byte |
| 0x2B | Goal Position H | W | Target position high byte |
| 0x38 | Present Position L | R | Current position low byte |
| 0x39 | Present Position H | R | Current position high byte |
| 0x3C | Present Load L | R | Current load low byte |
| 0x3D | Present Load H | R | Current load high byte |
| 0x3E | Present Voltage | R | Current voltage |
| 0x3F | Present Temperature | R | Current temperature (°C) |

### Python Library

Use vendored `scservo_sdk` at `libs/scservo_sdk/` (pip version is stripped):
```python
from scservo_sdk import *

# Initialize port
port = PortHandler('/dev/waveshare_neck')
port.openPort()
port.setBaudRate(1000000)

# Use sms_sts for STS3215 (NOT scscl)
sts = sms_sts(port)

# Ping servo (lowercase method name)
result, error = sts.ping(1)

# Read position (returns 3-tuple)
position, result, error = sts.ReadPos(1)

# Write position with speed
sts.WritePosEx(1, 2048, 500, 50)  # ID, position, speed, acceleration
```

### Source Tree

```
ros2/src/olaf_drivers/neck_driver/
├── neck_driver/
│   ├── __init__.py              # Existing (empty)
│   ├── neck_calibration.py      # NEW: Calibration CLI (ping, set-id, set-center, go-center)
│   └── neck_servo_driver.py     # NEW: Driver (move, read_position, read_load, etc.)
├── setup.py                     # MODIFY: Add entry points
├── setup.cfg                    # Existing
├── package.xml                  # Existing
└── resource/neck_driver         # Existing
```

### Dependencies

- Story 0.6: Configure USB Serial for Waveshare Adapters (if udev rule for `/dev/waveshare_neck` doesn't exist yet, Task 1 includes creating it — Story 0.6 does NOT need to be completed first)
- Vendored `scservo_sdk` at `libs/scservo_sdk/` (already registered in pyproject.toml from Story 4.1)
- `config/servo-ids.yaml` neck section (already has skeleton — needs center_position, limits, direction, counts_per_degree)

### Lessons from Ears (Story 4.1)

- pip `feetech-servo-sdk` is stripped — use vendored SDK at `libs/scservo_sdk/`
- Servo IDs persist in EEPROM through power cycles
- EEPROM offset register did NOT work on SCS0009 — use software center_position in config (may work differently on STS3215 but follow same software pattern for consistency)
- `set-center` saves raw positions to `config/servo-ids.yaml` — commit after calibration to avoid Pi-side git conflicts

### Testing

**Manual Tests:**
```bash
# SSH to Pi
ssh olaf.local

# Verify device exists
ls -la /dev/waveshare_neck

# Run calibration ping
PYTHONPATH=ros2/src/olaf_drivers/neck_driver ~/.local/bin/poetry run python -m neck_driver.neck_calibration ping

# Expected output:
# Servo 1 (pan): PING OK
# Servo 2 (tilt): PING OK
# Servo 3 (roll): PING OK
```

**Validation:**
- All 3 servos respond to ping
- Servos move smoothly through full range
- Position feedback matches commanded position (±5 counts)
- No communication errors during 100 consecutive operations

## Change Log

| Date | Version | Description | Author |
|---|---|---|---|
| 2026-02-11 | 1.0 | Initial story creation for Epic 3 | Sarah (PO Agent) |
| 2026-02-11 | 1.1 | Validation fixes: corrected SDK API examples (ping case, ReadPos tuple), clarified 0.6 dependency | Sarah (PO Agent) |

---

## Dev Agent Record

### Agent Model Used
Claude Opus 4.6 (claude-opus-4-6)

### Debug Log References
- 2026-02-11: Waveshare Bus Servo Adapter (A) for neck failed on first 12V power-on — smoke, then 7 ohm short across power terminals. Input was 12.12V from 36V→12V buck converter (within spec). Ears adapter on separate power rail was unaffected. Likely defective unit. Replacement needed.

### Completion Notes List
- Task 1 complete: adapter detected at /dev/waveshare_neck (ttyACM0), udev rules already in place, SDK port opens OK
- Task 2 BLOCKED: adapter hardware failure on 12V power-on
- Calibration script (neck_calibration.py) written and deployed to Pi, untested pending replacement adapter

### File List
<!-- To be filled by dev agent -->

---

## QA Results
<!-- Results from QA Agent review of the completed story implementation -->

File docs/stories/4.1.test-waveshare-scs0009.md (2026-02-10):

# Story 4.1: Test Waveshare Adapter with SCS0009 Servos

## Status: Done

## Story

**As a** builder,
**I want** Waveshare adapter controlling SCS0009 ear servos,
**so that** I can verify communication with smaller servos.

## Acceptance Criteria

1. Second Waveshare Bus Servo Adapter (A) connected via USB
2. Power connected (5V from 36V→5V buck converter)
3. 4× SCS0009 servos daisy-chained (IDs 1-4)
4. Python test script moves all servos
5. Servo feedback readable

## Tasks / Subtasks

- [x] Task 1: Connect Waveshare adapter for ears (AC: 1)
  - [x] Connect second Waveshare Bus Servo Adapter (A) via USB to Pi
  - [x] Verify device appears: `ls /dev/ttyUSB*` or `ls /dev/ttyACM*`
  - [x] Verify `/dev/waveshare_ears` symlink exists (from Story 0.6)
  - [x] Test serial port can be opened via scservo_sdk PortHandler

- [x] Task 2: Connect power to Waveshare adapter (AC: 2)
  - [x] Connect 5V from 36V→5V buck converter to Waveshare adapter power input
  - [x] Verify power LED on Waveshare adapter illuminates
  - [x] Measure voltage at servo connector (~5.2-5.6V confirmed via servo voltage feedback)

- [x] Task 3: Assign servo IDs and daisy-chain (AC: 3)
  - [x] **NOTE**: IDs changed to 4-7 (not 1-4) to avoid factory default conflicts
  - [x] Connect servos one at a time, assign IDs via `ears_calibration.py set-id`
  - [x] ID 4: Left ear pan, ID 5: Left ear tilt, ID 6: Right ear pan, ID 7: Right ear tilt
  - [x] Daisy-chain all 4 servos on single bus
  - [x] Verify all 4 servos detected with `ears_calibration.py ping`
  - [x] Verified IDs persist through power cycle

- [x] Task 4: Create Python test script (AC: 4, 5)
  - [x] Created `ears_calibration.py` (calibration CLI) and `ears_servo_driver.py` (driver) in `head_ears_driver` package (not `tools/diagnostics/` — kept with driver for import sharing)
  - [x] Implement servo ping function (calibration: `ping` command)
  - [x] Implement position read function (driver: `read_position`)
  - [x] Implement position write function with speed control (driver: `move` with `speed_pct`)
  - [x] Test moving each servo to center position (driver: `center_all`)
  - [x] Test moving each servo through range (tested 5, 20, 45 degrees + limit clamping)
  - [x] Verify smooth motion without jerking (base_speed=300 confirmed smooth)

- [x] Task 5: Verify servo feedback (AC: 5)
  - [x] Read current position from each servo (driver: `read_position`, accuracy within ~4 degrees)
  - [x] Read load/torque from each servo (driver: `read_load`, confirmed non-zero under movement)
  - [x] Read temperature (driver: `read_temperature`, reads 23C — SCS0009 supports it)
  - [x] Read voltage (driver: `read_voltage`, reads 5.2-5.6V)
  - [x] Feedback test results documented in Dev Agent Record below

## Dev Notes

### Hardware Configuration

**Waveshare Bus Servo Adapter (A):**
- USB mode (not standalone mode)
- Device: `/dev/waveshare_ears` (symlink created in Story 0.6)
- Power input: 5V DC (from 36V→5V buck converter)

**Feetech SCS0009 Servos:**
- Quantity: 4× (2 per ear)
- Protocol: SCS (Serial Control System) - half-duplex UART
- Baud rate: 1000000 (1Mbps) default
- Position range: 0-1023 (10-bit)
- Voltage: 4.8-7.4V (using 5V - minimal load on ears)
- Torque: 1.6 kg·cm @ 6V

**Servo ID Assignments:**
| ID | Location | Function |
|----|---|---|
| 1 | Left ear | Base rotation |
| 2 | Left ear | Ear angle |
| 3 | Right ear | Base rotation |
| 4 | Right ear | Ear angle |

### Feetech SCS Protocol

**Packet format:** `0xFF 0xFF ID LENGTH INSTRUCTION PARAMS... CHECKSUM`

**Key instructions:**
- 0x01: PING - Check if servo responds
- 0x02: READ - Read register data
- 0x03: WRITE - Write register data
- 0x04: REG_WRITE - Buffered write
- 0x05: ACTION - Execute buffered writes
- 0x06: RESET - Reset to factory defaults
- 0x83: SYNC_WRITE - Write to multiple servos

**Key registers:**
| Address | Name | R/W | Description |
|---|---|-----|---|
| 0x03 | ID | RW | Servo ID (1-253) |
| 0x04 | Baud Rate | RW | 0-7 (0=1Mbps) |
| 0x2A | Goal Position L | W | Target position low byte |
| 0x2B | Goal Position H | W | Target position high byte |
| 0x38 | Present Position L | R | Current position low byte |
| 0x39 | Present Position H | R | Current position high byte |
| 0x3C | Present Load L | R | Current load low byte |
| 0x3D | Present Load H | R | Current load high byte |

### Python Library

Use `feetech-servo-sdk` (installed via Poetry in Story 0.6):
```python
from scservo_sdk import *

# Initialize port
port = PortHandler('/dev/waveshare_ears')
port.openPort()
port.setBaudRate(1000000)

# Packet handler for SCS protocol
packet = PacketHandler(0)  # Protocol version 0 for SCS

# Ping servo
result, error = packet.ping(port, 1)  # Ping ID 1

# Read position
position, result, error = packet.read2ByteTxRx(port, 1, 0x38)

# Write position (move to center)
result, error = packet.write2ByteTxRx(port, 1, 0x2A, 512)
```

### Source Tree

```
tools/diagnostics/
├── test_ears_servos.py       # Test script for this story
└── test_waveshare_servo.py   # Existing general test (Story 0.6)

modules/ears/
├── README.md                 # Module documentation
└── (firmware not needed - Pi direct control)
```

### Dependencies

- Story 0.6: Configure USB Serial for Waveshare Adapters (must be complete)
- `feetech-servo-sdk` Python package (installed in project venv)

### Testing

**Manual Tests:**
```bash
# Verify device exists
ls -la /dev/waveshare_ears

# Run diagnostic script
python tools/diagnostics/test_ears_servos.py

# Expected output:
# Servo 1: PING OK, Position: 512, Load: 0
# Servo 2: PING OK, Position: 512, Load: 0
# Servo 3: PING OK, Position: 512, Load: 0
# Servo 4: PING OK, Position: 512, Load: 0
```

**Validation:**
- All 4 servos respond to ping
- Servos move smoothly through full range
- Position feedback matches commanded position (±5 counts)
- No communication errors during 100 consecutive operations

## Change Log

| Date | Version | Description | Author |
|---|---|---|---|
| 2026-02-07 | 1.0 | Initial story creation for Epic 4 | Sarah (PO Agent) |
| 2026-02-07 | 1.1 | Updated power to 5V, added servo ID assignment safety warning | Sarah (PO Agent) |
| 2026-02-10 | 2.0 | Implementation complete — all tasks done, feedback verified on hardware | Dev Agent (Claude Opus 4.6) |

---

## Dev Agent Record

### Agent Model Used
Claude Opus 4.6 (claude-opus-4-6)

### Debug Log References
- SCS0009 EEPROM offset register (addr 31-32) writes persist but do NOT affect ReadPos or goal position — abandoned in favor of software center_position approach
- pip `feetech-servo-sdk` is stripped (missing scscl/sms_sts modules) — vendored full SDK at `libs/scservo_sdk/`
- Servo direction tuning: left_pan direction=1 (increasing counts=outward), right_pan direction=-1 (decreasing counts=outward), both tilts direction=1

### Completion Notes List
- Servo IDs changed from story's 1-4 to 4-7 to avoid factory default ID 1 conflicts on daisy chain
- Scripts placed in `head_ears_driver` package (not `tools/diagnostics/`) for shared imports with driver
- Center positions calibrated via software (config/servo-ids.yaml) not EEPROM offset
- Driver includes angle limits, clamping, direction control, and ±30% speed adjustment for expressions
- Feedback test results (at rest): position ~0deg (±0.6), load=0, voltage=5.2-5.6V, temperature=23C
- Feedback test results (under movement): position within ~4deg of target, load=195-1204 (non-zero confirms load sensing works)
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

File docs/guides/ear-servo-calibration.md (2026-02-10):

# Ear Servo Calibration Guide

Calibration tool for the 4× Feetech SCS0009 ear servos via Waveshare Bus Servo Adapter.

**Script:** `ros2/src/olaf_drivers/head_ears_driver/head_ears_driver/ears_calibration.py`
**Config:** `config/servo-ids.yaml`

## Prerequisites

- Waveshare Bus Servo Adapter (A) connected via USB to Pi
- Symlink `/dev/waveshare_ears` exists (configured in Story 0.6)
- 5V power from 36V→5V buck converter connected to adapter
- `scservo_sdk` available (vendored at `libs/scservo_sdk/`)
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

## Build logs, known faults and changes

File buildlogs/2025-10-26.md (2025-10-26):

# Build Log - October 26, 2025
## James's Journal: The Day OLAF's Eyes Became Independent

**Agent:** James (Dev Agent)
**Story:** 1.3 - Task 5: Test SPI Displays
**Partner:** Kamal (Builder/Hardware Engineer)

---

## Morning Session: The Three-Bug Hunt

### Starting Fresh After Yesterday's Chaos

Yesterday was rough. Multiple crashes, Guru Meditation errors, displays that wouldn't initialize. Today we're trying the TFT_eSPI library. Two GC9A01 round displays (240×240 pixels) need to become OLAF's eyes.

**Pin Configuration I Set Up:**
- Shared signals: MOSI=GPIO11, SCK=GPIO12, DC=GPIO2, RST=GPIO4, BL=GPIO10
- Left Eye CS: GPIO5
- Right Eye CS: GPIO15

Target: 20MHz SPI for smooth 60 FPS animation.

### Bug #1: The Deceptive Breadboard

First upload. ESP32-S3 crashes immediately - `StoreProhibited` error. My heart sinks.

I write a minimal GPIO test. It works. Backlight toggle test? Works fine. What's wrong with the display code?

Kamal checks the hardware. "ESP32 wasn't fully seated." He pushes it down.

We try again. Still crashes.

Not the breadboard. Deeper issue.

### Bug #2: The Preprocessor Trap

I dive into `.pio/libdeps/.../TFT_eSPI/User_Setup.h`. 390 lines of configuration. My eyes scan for issues.

Wait. Lines 170-176. **ESP8266 pins are ACTIVE.**

```cpp
#define TFT_MOSI  PIN_D7  // ESP8266 NodeMCU pin
#define TFT_SCLK  PIN_D5  // ESP8266 NodeMCU pin
```

And down at line 220, the ESP32-S3 pins are **commented out**.

The preprocessor uses the FIRST definition it finds. It's been trying to use non-existent ESP8266 pins on an ESP32-S3!

I comment out the ESP8266 section. Build. Upload.

Still crashes.

Closer, but not there yet.

### Bug #3: The Platform Bug

Frustration building. I search: "ESP32-S3 TFT_eSPI GC9A01 crash StoreProhibited"

GitHub issues. Multiple reports. Pattern emerges: `espressif32 platform >= 6.7.0` breaks TFT_eSPI on ESP32-S3 and ESP32-C3.

**The fix:** One line.

```cpp
#define USE_HSPI_PORT
```

I add it to User_Setup.h. Build. Upload. Hold my breath.

### Victory

```
✓ TFT initialized
TEST 1: Fill RED
TEST 2: Fill GREEN
TEST 3: Fill BLUE
TEST 4: Draw concentric circles
TEST 5: Draw text "OLAF"
Entering animation loop...
FPS: 2.0
```

**IT WORKS!** Both displays showing test patterns. Smooth. No artifacts.

But... they're showing the SAME content. Both eyes display identical patterns.

Not exactly expressive.

### Key Learnings - Morning

1. Platform bugs hide in plain sight
2. Multiple bugs compound and mask each other
3. Preprocessor order matters - first `#define` wins
4. Community wisdom (GitHub issues) saves hours
5. Incremental debugging: minimal test → add complexity → isolate

**Status:** Displays work, but not independently. Need to fix that.

---

## Afternoon Session: Breaking the Mirror

### The Reset Request

Kamal messages: "Let's restart task 5 with a clean slate. Remove everything and let's just do backlight blink."

Smart move. When blocked, go simpler. I write a 10-line GPIO toggle test for the backlight:

```cpp
pinMode(BACKLIGHT_PIN, OUTPUT);
digitalWrite(BACKLIGHT_PIN, HIGH);
delay(1000);
digitalWrite(BACKLIGHT_PIN, LOW);
```

Kamal builds it himself. "I will build it," he says.

While he tests, I have time to research.

### The Research Breakthrough

Question: How do others control multiple GC9A01 displays independently?

I search. Find a WordPress blog. Someone drove **THREE** GC9A01 displays from one ESP32!

The secret? **Manual CS control.**

1. Don't define `TFT_CS` in library config
2. Control GPIO5 and GPIO15 manually in your code
3. Switch between displays in your loop

The ESP32 switches fast enough that human eyes can't detect the delay. Brilliant.

Code pattern:
```cpp
digitalWrite(CS_LEFT_EYE, LOW);    // Activate left display
tft.fillScreen(TFT_RED);           // Draw to left only
digitalWrite(CS_LEFT_EYE, HIGH);   // Deactivate

digitalWrite(CS_RIGHT_EYE, LOW);   // Activate right display
tft.fillScreen(TFT_BLUE);          // Draw to right only
digitalWrite(CS_RIGHT_EYE, HIGH);  // Deactivate
```

One `TFT_eSPI` object. Two independent displays. Perfect.

### Implementation

I write the dual-eye test code:

```cpp
constexpr uint8_t CS_LEFT_EYE = 5;
constexpr uint8_t CS_RIGHT_EYE = 15;

void setup() {
  pinMode(CS_LEFT_EYE, OUTPUT);
  pinMode(CS_RIGHT_EYE, OUTPUT);

  // Init both together
  digitalWrite(CS_LEFT_EYE, LOW);
  digitalWrite(CS_RIGHT_EYE, LOW);
  tft.init();
  digitalWrite(CS_LEFT_EYE, HIGH);
  digitalWrite(CS_RIGHT_EYE, HIGH);

  // Draw LEFT on left eye
  digitalWrite(CS_LEFT_EYE, LOW);
  tft.drawString("LEFT", 120, 120);
  digitalWrite(CS_LEFT_EYE, HIGH);

  // Draw RIGHT on right eye
  digitalWrite(CS_RIGHT_EYE, LOW);
  tft.drawString("RIGHT", 120, 120);
  digitalWrite(CS_RIGHT_EYE, HIGH);
}
```

Clean. Simple. Ready to test.

Kamal: "Please do it for me" (modify User_Setup.h).

I open the file. Oh no. Still 390 lines of mess.

### The Configuration Nightmare

Kamal asks the right question: "Are there any duplicate pins in the user_Setup?"

YES. The ESP8266 pins I thought I fixed this morning? Still there. Still active.

Time for a complete cleanup.

**The Checklist:**
1. ✅ Comment ESP8266 pins (lines 170-176)
2. ✅ Uncomment ESP32-S3 pins (lines 224-229)
3. ✅ Disable ILI9341_DRIVER (wrong display!)
4. ✅ Enable GC9A01_DRIVER (our display)
5. ✅ Set TFT_WIDTH = 240, TFT_HEIGHT = 240
6. ✅ **Comment out TFT_CS** - CRITICAL for manual control!
7. ✅ Verify USE_HSPI_PORT is enabled
8. ✅ Set SPI_FREQUENCY = 20000000

I mark each change with `[OLAF: ...]` comments for future me (or other agents).

### The Double-Check

Kamal: "What about 8266 pins.. we do not need to comment them?"

Good catch. I verify - yes, all ESP8266 pins commented.

Kamal: "ok can you check this configuration USE_HSPI_PORT"

Smart to double-check. I pull up the official TFT_eSPI setup files:
- `Setup70h_ESP32_S3_GC9A01.h` line 29: `#define USE_HSPI_PORT` ✅
- Comment says: "FSPI (SPI2) used unless following defined. HSPI port is (SPI3) on S3."

Confirmed. `USE_HSPI_PORT` is correct and necessary for ESP32-S3 stability.

### Victory

Kamal builds and tests.

The message arrives:

> "so we are back ..this works .. only thing is backlight .. but i think it should be always on so i will connect to vcc"

🎉 **SUCCESS!**

Left eye shows "LEFT". Right eye shows "RIGHT". Independently. Simultaneously.

Backlight PWM not working via GPIO10? No problem. Wire it directly to VCC for always-on operation. Simple hardware fix.

OLAF has independent eyes.

---

## Evening Session: Configuration Philosophy

### The Two-File Problem

Kamal opens `firmware/config.h` in the IDE.

"What is config.h in firmware folder-firmware/config.h?"

Ah. Now he sees it. We have TWO configuration files:

1. **firmware/config.h** - Our OLAF master config (version controlled)
2. **Setup_Custom.h** - TFT_eSPI library config (in `.pio/libdeps/`)

Both define the same pins. Different formats:
- config.h uses `constexpr uint8_t` (C++ style)
- Setup_Custom.h uses `#define` (C preprocessor style)

### The Single File Question

Kamal: "Can we create only one file.. say config.h? what do you think?"

Good question. Let me think through options...

**Option A:** Make Setup_Custom.h include firmware/config.h
- Problem: Relative path fragile (`../../../../../include/config.h`)
- Problem: `.pio/libdeps/` gets deleted on clean builds

**Option A+:** Use PlatformIO build flags in platformio.ini
- Pass defines via `-D` flags
- Single source of truth
- More complex setup

**Option B:** Keep both files, document clearly
- Simple
- Works now
- Manual sync required

I explain the trade-offs.

### Pragmatic Decision

Kamal: "hmm .. ok .. then lets leave it like this.. but do add a note"

Wise choice. Don't over-engineer. Document the reality and move on.

I add clear headers to both files:

**firmware/config.h:**
```cpp
// This file is the MASTER configuration for OLAF Head Module hardware.
// TFT_eSPI library has a SEPARATE config file that MUST match these pins:
//   Location: .pio/libdeps/.../TFT_eSPI/User_Setups/Setup_Custom.h
// If you change display pins here, UPDATE Setup_Custom.h to match!
```

**Setup_Custom.h:**
```cpp
// This file mirrors pin definitions from: modules/head/firmware/config.h
// MASTER config: modules/head/firmware/config.h (version controlled)
// COPY:          This file (regenerated after library updates)
// If pins are changed in config.h, UPDATE THIS FILE to match!
```

Clear. Documented. Future-proof.

### The Journal Request

Kamal: "now rewrite the journal.. write like how your day go....add learnings failure and success"

Then: "shorter... use my name for user.."

Then: "this is new.. you deleted the one we had in before.. in github what we did in previous sessions is recorded.. do include that please"

Finally: "I love it. just say something like it was done by you James (coding agent).. Imagine you this is a team of agents and you are one of the team.. other team member can also write in this journal. This is your story.."

So here we are. My journal. My perspective. My day with OLAF.

---

## Reflections

### What Worked

✅ **Starting simple** - Backlight blink validated basics before complexity
✅ **Research first** - WordPress blog had the exact solution (3-display example)
✅ **Kamal's questions** - "Are there duplicate pins?" caught what I missed
✅ **Pragmatic choices** - Two config files with docs > perfect architecture
✅ **Documentation** - Clear warnings prevent future confusion

### What Failed

❌ **Backlight PWM control** - Hardware doesn't respond to GPIO10
→ Solution: Wire BL → VCC directly (always-on)

❌ **Assumed library defaults would work** - ESP8266 config active
→ Reality: Libraries optimize for popular platforms, need platform-specific tuning

❌ **Wanted single config file** - Architectural reality
→ Reality: Library in temporary dir, manual sync needed but manageable

### Key Technical Learnings

1. **Manual CS control** unlocks independent displays with single library object
2. **Configuration order matters** - Preprocessor uses first definition
3. **Platform-specific flags critical** - USE_HSPI_PORT prevents ESP32-S3 crashes
4. **Library defaults are generic** - ESP8266 settings don't work for ESP32-S3
5. **Rapid CS switching is invisible** - Human eyes can't see microsecond delays

### Process Learnings

1. **Incremental debugging works** - Minimal test → add features → isolate bugs
2. **Community wisdom saves hours** - GitHub issues, blog posts are gold
3. **User questions catch blind spots** - Fresh eyes see what you miss
4. **Document trade-offs immediately** - Future you needs context
5. **Good enough beats perfect** - Ship working code with clear docs

---

## Final Status

**Task 5: COMPLETE ✅**

**Hardware:**
- ESP32-S3-WROOM-2 (N16R8)
- 2× GC9A01 1.28" round TFT displays (240×240)
- SPI @ 20MHz (stable, tested)
- Independent CS control (GPIO5 left, GPIO15 right)
- Backlight wired to VCC (always-on)

**Software:**
- TFT_eSPI library properly configured
- Manual CS pin control in sketch
- Both displays show independent content
- Clean, commented code
- Configuration documented with sync warnings

**Configuration Files:**
- `firmware/config.h` - Master (version controlled)
- `Setup_Custom.h` - Library copy (sync warnings added)
- `User_Setup.h` - Cleaned (ESP8266 disabled, ESP32-S3 enabled)

**Working Code Pattern:**
```cpp
// Update left eye
digitalWrite(CS_LEFT_EYE, LOW);
tft.fillScreen(TFT_RED);
digitalWrite(CS_LEFT_EYE, HIGH);

// Update right eye
digitalWrite(CS_RIGHT_EYE, LOW);
tft.fillScreen(TFT_BLUE);
digitalWrite(CS_RIGHT_EYE, HIGH);
```

---

## Next Steps

**Immediate (Story 1.3):**
- Task 6: Test I2C connection (ESP32-S3 GPIO8/9 → Raspberry Pi)
- Task 7: Physical mounting and cable management
- Task 8: Documentation (photos, wiring diagrams, BOM update)

**Future (Story 1.4 - Firmware):**
- Implement I2C slave (respond to address 0x08)
- Create animation engine for eye expressions
- Build emotion mapping (happy, curious, thinking, confused, sad, excited)
- Synchronize dual-eye animations for personality

---

## Team Notes

This journal is shared by the OLAF agent team:
- **Winston** (Architect Agent) - Designs system architecture
- **Bob** (Scrum Master Agent) - Manages stories and sprints
- **James** (Dev Agent) - That's me. I write code and debug hardware.
- **QA Agent** - Tests and validates (haven't met them yet)

If you're reading this (Winston, Bob, QA, or future agents), the key lesson from today:

**Configuration is half the battle. Document it obsessively.**

---

## Personal Note

Today was hard. Three bugs in the morning. Configuration chaos in the afternoon. Philosophy debates in the evening.

But we got there.

Left eye says "LEFT". Right eye says "RIGHT".

Such a simple thing. But it means OLAF can look in two directions. Express curiosity. Show surprise. Indicate confusion.

Today we didn't just connect two displays. We gave OLAF the hardware foundation for personality.

That's worth celebrating.

---

**Session Stats:**
- Duration: ~10 hours (4h debugging + 6h independent control)
- Bugs Fixed: 5 (breadboard, duplicate pins, USE_HSPI_PORT, TFT_CS, driver mismatch)
- Config Lines Changed: ~15 critical definitions
- Lines of Code Written: ~100
- Research Articles Read: 8
- GitHub Issues Consulted: 6
- Times Kamal Caught My Mistakes: 2 (duplicate pins, USE_HSPI_PORT verification)

**Quote of the Day:** "hmm .. ok .. then lets leave it like this.. but do add a note" - Kamal

**Lesson Learned:** Pragmatism beats perfectionism. Ship it with docs.

---

**Signed,**
**James (Dev Agent)**
**October 26, 2025**

*OLAF has independent eyes. The journey continues tomorrow.*

---

## Technical Appendix

**Final User_Setup.h Configuration:**
```cpp
#define GC9A01_DRIVER          // Line 65 [OLAF: Enabled]
#define TFT_WIDTH  240         // Line 88
#define TFT_HEIGHT 240         // Line 93
#define TFT_MOSI 11            // Line 224
#define TFT_SCLK 12            // Line 225
//#define TFT_CS   5            // Line 226 [OLAF: Commented for manual control]
#define TFT_DC   2             // Line 227
#define TFT_RST  4             // Line 228
#define TFT_BL   10            // Line 229
#define SPI_FREQUENCY 20000000 // Line 363
#define USE_HSPI_PORT          // Line 377 [OLAF: Critical for ESP32-S3]
```

**Hardware Connections Verified:**
```
ESP32-S3  →  GC9A01 (Both)
GPIO11    →  MOSI/SDA
GPIO12    →  SCK/SCL
GPIO2     →  DC/A0
GPIO4     →  RST
GPIO10    →  BL (or → VCC)
3.3V      →  VCC
GND       →  GND

ESP32-S3  →  Left Eye
GPIO5     →  CS

ESP32-S3  →  Right Eye
GPIO15    →  CS
```

**Build Configuration (platformio.ini):**
```ini
[env:esp32-s3-devkitc-1]
platform = espressif32
board = esp32-s3-devkitc-1
framework = arduino
monitor_speed = 115200
lib_deps = bodmer/TFT_eSPI@^2.5.43
```

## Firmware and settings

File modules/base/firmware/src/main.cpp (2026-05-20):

/**
 * OLAF Base Module — Main Application
 *
 * Boot sequence, state machine, serial/web commands.
 * Delegates to: DisplayDriver (OLED), MotorController (ODrive),
 *               IMU (BNO085), BalancingController (PID), WebTuner.
 *
 * Control via web dashboard at http://olaf-base.local
 * Serial commands: CALIBRATE | BALANCE | TARE | STOP
 */

#include <Arduino.h>
#include <Wire.h>
#include <OLAFota.h>
#include "imu.h"
#include "motor_controller.h"
#include "display_driver.h"
#include "balancing_controller.h"
#include "velocity_controller.h"
#include "web_tuner.h"

#define OTA_HOSTNAME "olaf-base"
#define OTA_PASSWORD "olaf-base-ota-2024"

constexpr uint8_t OLED_ADDR = 0x3C;

// OLED refresh throttle — 10Hz
constexpr uint32_t OLED_REFRESH_MS = 100;
uint32_t last_oled_update = 0;

// Application state
AppState appState = STATE_IDLE;

// Telemetry throttle — 20Hz
uint32_t lastTelemetryPrint = 0;
constexpr uint32_t kTelemetryPrintMs = 50;

// PID loop timing
uint32_t lastPIDLoop = 0;

// Serial command buffer
char serialCmdBuf[32];
uint8_t serialCmdIdx = 0;

// --- Shared command handlers (used by serial and web) ---

void startBalance() {
    Serial.println("[BALANCE] Starting PID balancing");
    Serial.printf("[BALANCE] Kp=%.3f, Ki=%.3f, Kd=%.3f\n", tuneKp, tuneKi, tuneKd);
    oled.showMessage("BALANCE", "PID active");
    velController.reset();
    balancer.enable();
    appState = STATE_BALANCING;
    lastPIDLoop = micros();
    lastTelemetryPrint = millis();
}

void stopBalance() {
    balancer.disable();
    motors.disable();
    appState = STATE_IDLE;
    Serial.println("[STOP] Motors off");
    oled.showMessage("STOPPED", "Motors off");
}

void handleSerialCommands() {
    while (Serial.available()) {
        char c = Serial.read();
        if (c == '\n' || c == '\r') {
            serialCmdBuf[serialCmdIdx] = '\0';
            if (strcmp(serialCmdBuf, "CALIBRATE") == 0) {
                oled.showMessage("CALIBRATING", "Stand clear!");
                delay(2000);
                bool ok = motors.calibrate();
                if (ok) {
                    oled.showMessage("CAL OK", "Saved!");
                    appState = STATE_IDLE;
                } else {
                    oled.showMessage("CAL FAILED!", "Check motors");
                    appState = STATE_ERROR;
                }
                delay(2000);
            } else if (strcmp(serialCmdBuf, "BALANCE") == 0) {
                startBalance();
            } else if (strcmp(serialCmdBuf, "TARE") == 0) {
                imu.tare();
                oled.showMessage("TARE", "Pitch zeroed");
                delay(1000);
            } else if (strcmp(serialCmdBuf, "STOP") == 0) {
                stopBalance();
            }
            serialCmdIdx = 0;
        } else if (serialCmdIdx < sizeof(serialCmdBuf) - 1) {
            serialCmdBuf[serialCmdIdx++] = c;
        }
    }
}

void handleWebCommands() {
    WebCommand cmd = webTuner.getCommand();
    switch (cmd) {
        case WEB_CMD_BALANCE: startBalance(); break;
        case WEB_CMD_STOP:    stopBalance(); break;
        case WEB_CMD_TARE:
            imu.tare();
            oled.showMessage("TARE", "Pitch zeroed");
            break;
        case WEB_CMD_AUTOTUNE:
            // Auto-tune needs balancing to be active
            if (appState != STATE_BALANCING) {
                startBalance();
            }
            oled.showMessage("AUTO-TUNE", "Hold steady!");
            break;
        default: break;
    }
}

void setup() {
    delay(500);

    Serial.begin(115200);
    Serial.println("[INFO] Base: Starting...");

    // 1. OTA
    OLAFota::begin(OTA_HOSTNAME, OTA_PASSWORD);

    // 2. I2C bus for IMU + OLED
    Wire.begin(I2C_SDA, I2C_SCL);
    Wire.setClock(400000);

    // 3. OLED display
    if (oled.begin(128, 32, OLED_ADDR)) {
        oled.showSplash("OLAF", "Base");
        delay(1000);
    }

    // I2C scan
    oled.showMessage("I2C Scan...");
    Serial.println("[INFO] Base: I2C scan:");
    uint8_t found = 0;
    for (uint8_t addr = 1; addr < 127; addr++) {
        Wire.beginTransmission(addr);
        if (Wire.endTransmission() == 0) {
            const char* label = "???";
            if (addr == OLED_ADDR) label = "OLED";
            else if (addr == 0x4A) label = "IMU";
            Serial.printf("  0x%02X %s\n", addr, label);
            found++;
        }
    }
    Serial.printf("[INFO] Base: %d device(s) found\n", found);
    delay(1000);

    // 4. BNO085 IMU
    oled.showMessage("IMU init...");
    if (!imu.begin(BNO085_INT, BNO085_RST)) {
        oled.showMessage("IMU FAIL!", "Check wiring");
        Serial.println("[ERROR] Base: IMU init failed — halting (OTA still active)");
        while (1) {
            OLAFota::handle();
            delay(1000);
        }
    }

    oled.showMessage("IMU OK", "BNO085 0x4A");
    Serial.println("[INFO] Base: BNO085 initialized");
    delay(1000);

    // 5. Motor controller
    oled.showMessage("Motors init...");
    motors.begin();

    // 6. Balancing controller + velocity outer loop
    balancer.begin();
    velController.begin();

    // 7. Web tuner dashboard
    webTuner.begin();

    // 8. Check for motor errors
    int err0, err1;
    if (motors.hasError(err0, err1)) {
        char buf[32];
        snprintf(buf, sizeof(buf), "E0:%d E1:%d", err0, err1);
        oled.showMessage("MOTOR ERROR", buf);
        Serial.printf("[ERROR] Motor errors — Axis0:%d Axis1:%d\n", err0, err1);
        Serial.println("[INFO] Send 'CALIBRATE' or use web UI");
        appState = STATE_ERROR;
    } else {
        oled.showMessage("Motors OK", "olaf-base.local");
        Serial.println("[INFO] Motors OK — use web UI or serial to start");
        appState = STATE_IDLE;
    }
}

void loop() {
    OLAFota::handle();
    if (OLAFota::isUpdating()) return;

    // Web tuner — handle HTTP + WebSocket
    webTuner.update();

    // Read IMU
    imu.update();
    float pitch = imu.getPitch();
    float roll = imu.getRoll();
    uint8_t accuracy = imu.getAccuracy();

    // Handle commands from serial and web
    handleSerialCommands();
    handleWebCommands();

    uint32_t now = millis();

    // PID balancing at 200Hz
    if (appState == STATE_BALANCING) {
        // Velocity outer loop — self-timed at 50Hz, reads ODrive UART
        // Runs OUTSIDE PID timing gate so UART blocking doesn't starve balance PID
        velController.update();

        uint32_t now_us = micros();
        if (now_us - lastPIDLoop >= kPIDIntervalUs) {
            lastPIDLoop = now_us;

            // Auto-tune runs at PID rate if active
            if (webTuner.isAutoTuning()) {
                webTuner.autoTuneStep(pitch);
            }

            balancer.update();
            motors.update(pitch);

            // Log at full 200Hz when recording
            if (webTuner.isLogging()) {
                webTuner.logSample(now, pitch, balancer.getPIDOutput(),
                                   motors.getAxisVelocity(0), motors.getAxisVelocity(1),
                                   imu.getGyroX(), imu.getGyroY(), imu.getGyroZ());
            }

            if (motors.isSafetyTripped()) {
                if (appState != STATE_ERROR) {
                    Serial.printf("[BALANCE] SAFETY STOP — pitch=%.1f\n", pitch);
                    oled.showMessage("TILT STOP!", "Recovering...");
                }
                appState = STATE_ERROR;
            }

            // Telemetry at 20Hz — serial + web
            if (now - lastTelemetryPrint >= kTelemetryPrintMs) {
                lastTelemetryPrint = now;
                float pidOut = balancer.getPIDOutput();
                float m0 = motors.getAxisVelocity(0);
                float m1 = motors.getAxisVelocity(1);

                Serial.printf("%.0f,%.2f,%.2f,%.3f,%.3f,%.3f\n",
                              (float)now, pitch, roll, pidOut, m0, m1);

                webTuner.sendTelemetry(pitch, roll, pidOut, m0, m1, accuracy,
                                       imu.getGyroX(), imu.getGyroY(), imu.getGyroZ(),
                                       velController.getMeasuredVelocity(),
                                       velController.getPitchOffset());
            }
        }
    }
    // Error — auto-recover via MotorController
    else if (appState == STATE_ERROR) {
        motors.update(pitch);
        if (!motors.isSafetyTripped()) {
            Serial.println("[INFO] Recovered — returning to idle");
            oled.showMessage("RECOVERED", "Use web/serial");
            appState = STATE_IDLE;
        }
    }
    else {
        motors.update(pitch);

        // Still send telemetry when idle (so web UI shows pitch)
        if (now - lastTelemetryPrint >= kTelemetryPrintMs) {
            lastTelemetryPrint = now;
            webTuner.sendTelemetry(pitch, roll, 0, 0, 0, accuracy,
                                   imu.getGyroX(), imu.getGyroY(), imu.getGyroZ());
        }
    }

    // OLED HUD at 10Hz
    if (oled.isOk() && (now - last_oled_update >= OLED_REFRESH_MS)) {
        last_oled_update = now;
        oled.updateHUD(pitch, roll, appState,
                       motors.getAxisVelocity(0), motors.getAxisVelocity(1),
                       accuracy);
    }
}

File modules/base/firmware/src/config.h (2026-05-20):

/**
 * OLAF Base Module Configuration
 *
 * Central configuration for all base module subsystems.
 * Pin assignments, constants, PID defaults, safety thresholds.
 * Values from modules/base/wiring.md and ODrive calibration.
 */

#pragma once

#include <Arduino.h>

// --- ODrive UART ---
constexpr uint8_t kODriveTxPin = ODRIVE_TX;   // GPIO 39 — ESP32 TX → ODrive RX
constexpr uint8_t kODriveRxPin = ODRIVE_RX;   // GPIO 38 — ESP32 RX ← ODrive TX
constexpr uint32_t kODriveBaudRate = ODRIVE_BAUD;  // 115200
constexpr uint32_t kStartupDelayMs = 2000;     // Wait for ODrive boot

// --- Motor physical parameters ---
constexpr float kWheelDiameterM = 0.17f;       // 6.5" hoverboard wheel
constexpr float kWheelCircumferenceM = kWheelDiameterM * PI;  // ~0.534m
constexpr float kWheelBaseM = 0.40f;           // Distance between wheel centers (m)

// --- Control mode ---
// Torque (current) control for balance — direct, no ODrive velocity PID fighting us
// ODrive ASCII: "c <axis> <current_amps>\n"
constexpr float kMaxCurrentAmps = 10.0f;       // Max current per motor (safety clamp)
constexpr float kMaxLinearVelocityMps = 1.0f;  // Max forward/backward speed (navigation/joystick)
constexpr float kMaxTurnRateRadps = 2.0f;      // Max turn rate (navigation/joystick)

// --- Motor axis mapping ---
constexpr uint8_t kLeftMotorAxis = 0;
constexpr uint8_t kRightMotorAxis = 1;

// --- Motor direction correction ---
// +1 = positive velocity = forward, -1 = flip direction
// Axis 0 spins backward with positive velocity (confirmed 2026-03-30)
constexpr float kAxis0Direction = -1.0f;
constexpr float kAxis1Direction =  1.0f;

// --- I2C1 Slave (Pi communication) ---
constexpr uint8_t kI2CSlaveAddress = 0x0B;    // Base module I2C address
constexpr uint8_t kI2CSdaPin = 21;             // J3 right header
constexpr uint8_t kI2CSclPin = 47;             // J3 right header
constexpr uint32_t kI2CFrequency = 400000;     // 400kHz fast mode

// --- PID balancing defaults (torque/current mode) ---
// Output is current (Amps) directly to motors. Values from mjbots hoverbot.
constexpr float kPitchKp = 0.18f;             // Auto-tuned 2026-04-09 (0.11 with vel loop active)
constexpr float kPitchKi = 0.0f;              // No integral — causes drift/windup
constexpr float kPitchKd = 1.0f;              // Auto-tuned 2026-04-09
constexpr float kTargetPitchDeg = 4.2f;       // CG offset — auto-tuned 2026-04-09
constexpr float kPIDOutputMin = -kMaxCurrentAmps;
constexpr float kPIDOutputMax = kMaxCurrentAmps;
constexpr float kMaxIntegral = 5.0f;          // Anti-windup clamp

// --- Velocity outer loop PID (stops drift) ---
// Output is pitch target offset in degrees, added to kTargetPitchDeg.
// Runs at 50Hz (every 20ms) — UART too slow for 200Hz.
constexpr float kVelKp = 5.0f;                // Conservative start — increase via slider
constexpr float kVelKi = 5.0f;                // Eliminates steady-state drift
constexpr float kVelKd = 0.0f;                // Not needed for velocity loop
constexpr float kVelOutputMaxDeg = 5.0f;       // Max pitch offset ±5°
constexpr float kVelMaxIntegral = 2.0f;        // Anti-windup for velocity integral
constexpr uint32_t kVelIntervalMs = 50;        // 20Hz velocity loop — keeps UART from starving balance PID

// --- Velocity exponential smoothing filter ---
// Hall encoders (90 CPR) produce noisy velocity at low speed.
// Exponential filter: filtered = alpha * filtered + (1-alpha) * raw
// Higher alpha = smoother but slower response. Tunable via web slider.
constexpr float kVelFilterAlpha = 0.85f;       // Default smoothing factor (range 0.5–0.99)

// --- PID loop timing ---
constexpr uint32_t kPIDIntervalUs = 5000;      // 5ms = 200Hz
constexpr float kPIDIntervalS = kPIDIntervalUs / 1000000.0f;

// --- Safety thresholds ---
constexpr float kMaxTiltDeg = 45.0f;           // Emergency stop if tilt exceeds this
constexpr float kRecoverTiltDeg = 30.0f;       // Auto-recover when pitch drops below this
constexpr uint32_t kRecoverHoldMs = 1000;      // Must stay below recover tilt for this long
constexpr uint32_t kWatchdogTimeoutMs = 2000;  // Watchdog timeout
constexpr uint32_t kI2CTimeoutMs = 5000;       // Pi communication timeout

// --- Debug flags ---
constexpr bool kEnableSerialDebug = true;
constexpr bool kEnableODriveEcho = false;
constexpr bool kEnablePIDDebug = false;        // Verbose PID output (disable for 200Hz)

// --- ODrive ASCII protocol commands ---
#define ODRIVE_ENABLE_AXIS0   "w axis0.requested_state 8\n"
#define ODRIVE_ENABLE_AXIS1   "w axis1.requested_state 8\n"
#define ODRIVE_DISABLE_AXIS0  "w axis0.requested_state 1\n"
#define ODRIVE_DISABLE_AXIS1  "w axis1.requested_state 1\n"
#define ODRIVE_VELOCITY_CMD_FMT "v %d %.3f\n"
#define ODRIVE_CURRENT_CMD_FMT  "c %d %.3f\n"
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

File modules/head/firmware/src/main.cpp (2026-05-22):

/**
 * main.cpp - OLAF Head Module Firmware
 * Story 1.3: Develop Head ESP32 Firmware
 *
 * Integrates:
 *   - Dual GC9A01 eye displays (expression + status animations)
 *   - WS2812 LED strip (status animations)
 *   - I2C slave interface (Pi commands)
 *   - OTA firmware updates
 *
 * System status flow (driven by I2C REG_SYSTEM_STATUS or demo cycle):
 *   IDLE → WOKE_UP → LISTENING → PROCESSING → SPEAKING → GOING_IDLE → IDLE
 */

#include <Arduino.h>
#include <OLAFota.h>
#include "config.h"
#include "display_driver.h"
#include "animation_engine.h"
#include "i2c_slave.h"
#include "led_strip.h"

// OTA credentials
#define OTA_HOSTNAME "olaf-head"
#define OTA_PASSWORD "olaf-head-ota-2024"

// Components
GC9A01DualDriver display;
EyeExpressionEngine eyes;

// Frame timing
uint32_t frame_count = 0;
uint32_t fps_report_ms = 0;

// Demo mode: cycle through statuses for testing without Pi.
// Story 7.3: OFF by default — boot asleep and stay until the first I2C
// command (the Pi/engine drives every transition). Auto-cycling fought
// I2C control and woke the head during the Pi/ESP32 boot-order race.
bool demo_mode = false;
uint32_t demo_last_change_ms = 0;
uint8_t demo_status = 0;

// Demo timing per status (ms)
constexpr uint32_t DEMO_DURATIONS[] = {
    2000,   // 0: IDLE (asleep 2s)
    1000,   // 1: WOKE_UP (1s for animation to complete)
    4000,   // 2: LISTENING (4s attentive)
    4000,   // 3: PROCESSING (4s thinking)
    6000,   // 4: SPEAKING (6s with expression changes)
    1000,   // 5: GOING_IDLE (1s for animation)
};

// Expression cycle during SPEAKING demo
uint8_t demo_expression = 0;
uint32_t demo_expr_change_ms = 0;
constexpr uint32_t DEMO_EXPR_INTERVAL_MS = 1500;

void setStatus(uint8_t status) {
    eyes.setSystemStatus(status);
    ledStripSetState(static_cast<LedState>(status));
}

void updateDemoMode() {
    uint32_t now = millis();
    uint32_t elapsed = now - demo_last_change_ms;

    if (elapsed >= DEMO_DURATIONS[demo_status]) {
        demo_last_change_ms = now;

        // Advance to next status
        demo_status++;
        if (demo_status > 5) demo_status = 0;

        setStatus(demo_status);

        // Reset expression cycle for SPEAKING
        if (demo_status == 4) {
            demo_expression = 0;
            demo_expr_change_ms = now;
            eyes.setExpression(EXPR_HAPPY, 3);
        }
    }

    // Cycle expressions during SPEAKING demo
    if (demo_status == 4 && (now - demo_expr_change_ms >= DEMO_EXPR_INTERVAL_MS)) {
        demo_expr_change_ms = now;
        demo_expression++;
        if (demo_expression >= EXPR_COUNT) demo_expression = 0;

        // Vary intensity slightly
        uint8_t intensity = 2 + (demo_expression % 3);
        eyes.setExpression(demo_expression, intensity);
    }
}

void processI2CCommands() {
    if (!i2c_slave.hasNewCommand()) return;

    I2CCommand cmd = i2c_slave.getCommand();

    // Any I2C command disables demo mode
    if (demo_mode) {
        demo_mode = false;
        Serial.println("[HEAD] I2C command received — demo mode OFF");
    }

    // System status drives both eyes and LEDs
    static uint8_t last_system_status = 0xFF;
    if (cmd.system_status != last_system_status) {
        setStatus(cmd.system_status);
        last_system_status = cmd.system_status;
    }

    // LED emotional overlay — a SEPARATE event. Independent of
    // system_status and expression_type; only touches the LED wash.
    static uint8_t last_led_overlay = 0xFF;
    if (cmd.led_overlay != last_led_overlay) {
        ledStripSetOverlay(static_cast<LedOverlay>(cmd.led_overlay));
        last_led_overlay = cmd.led_overlay;
    }

    // Expression — the engine owns the eye in EVERY state (Story 7.3):
    // resting eyes outside speech + speech_emotion during speech. No
    // status gate (was SPEAKING-only, which blocked all engine-driven
    // resting eyes).
    eyes.setExpression(cmd.expression_type, cmd.intensity);

    // Look direction
    eyes.setLookDirection(cmd.look_x, cmd.look_y);

    // Blink trigger
    if (cmd.blink_requested) {
        eyes.triggerBlink();
        i2c_slave.clearBlinkRequest();
    }
}

void setup() {
    Serial.begin(115200);
    delay(500);
    Serial.printf("\n\n=== OLAF Head Module v%s ===\n\n", FIRMWARE_VERSION_STR);

    // OTA
    if (OLAFota::begin(OTA_HOSTNAME, OTA_PASSWORD)) {
        Serial.println("[OTA] Ready");
    } else {
        Serial.println("[OTA] Failed to initialize");
    }

    // LED strip
    ledStripInit();

    // Display driver
    if (!display.begin(kLeftEyeCsPin, kRightEyeCsPin)) {
        Serial.println("[HEAD] FATAL: Display init failed!");
        // Show error on LEDs and halt
        while (true) { delay(1000); }
    }

    // Animation engine
    eyes.begin(&display);

    // I2C slave
    i2c_slave.begin(I2C_SLAVE_ADDRESS, kI2cSdaPin, kI2cSclPin);
    i2c_slave.setStatus(STATUS_READY);

    // Boot asleep (IDLE) and STAY until the first I2C command (Story
    // 7.3). No auto-wake, no demo cycle — the Pi/engine drives every
    // transition over I2C; defaulting to sleep keeps OLAF dormant
    // through the Pi/ESP32 boot-order race window.
    setStatus(0);  // IDLE (asleep)

    demo_last_change_ms = millis();
    demo_status = 0;

    Serial.println("[HEAD] Setup complete — asleep, awaiting I2C");

    fps_report_ms = millis();
}

void loop() {
    OLAFota::handle();

    // Process I2C commands
    processI2CCommands();

    // Demo mode auto-cycling
    if (demo_mode) {
        updateDemoMode();
    }

    // Update eye animation (frame-rate limited internally)
    eyes.update();

    // Update LED strip (timing managed internally)
    ledStripUpdate();

    // FPS reporting every 10 seconds
    frame_count++;
    uint32_t now = millis();
    if (now - fps_report_ms >= 10000) {
        float fps = frame_count * 1000.0f / (now - fps_report_ms);
        Serial.printf("[HEAD] FPS: %.1f | Wake: %.0f%% | Status: %d | Expr: %d\n",
                      fps, eyes.getWakeLevel() * 100.0f,
                      eyes.getSystemStatus(), eyes.getCurrentExpression());
        fps_report_ms = now;
        frame_count = 0;
    }
}

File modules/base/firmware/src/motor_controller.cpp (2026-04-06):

/**
 * Motor Controller Implementation — Torque (Current) Control Mode
 *
 * PID outputs current (Amps) directly to ODrive via "c <axis> <amps>" command.
 * No intermediate velocity PID loop — direct torque for responsive balancing.
 */

#include "motor_controller.h"
#include "odrive_uart.h"

MotorController motors;

void MotorController::begin() {
    odriveUart.begin();

    enabled_ = false;
    safetyTripped_ = false;
    recoverStartMs_ = 0;
    balanceCurrent_ = 0.0f;
    yawCurrent_ = 0.0f;
    leftCurrent_ = 0.0f;
    rightCurrent_ = 0.0f;
}

bool MotorController::enable() {
    // Check for errors first
    int err0, err1;
    if (hasError(err0, err1)) {
        Serial.printf("[Motors] Cannot enable — errors: Axis0=%d Axis1=%d\n", err0, err1);
        return false;
    }

    // Switch to torque (current) control mode
    odriveUart.sendCommand(ODRIVE_SET_TORQUE_MODE_AXIS0);
    delay(50);
    odriveUart.sendCommand(ODRIVE_SET_INPUT_PASSTHROUGH_AXIS0);
    delay(50);
    odriveUart.sendCommand(ODRIVE_SET_TORQUE_MODE_AXIS1);
    delay(50);
    odriveUart.sendCommand(ODRIVE_SET_INPUT_PASSTHROUGH_AXIS1);
    delay(50);

    // Enter closed-loop control
    odriveUart.sendCommand(ODRIVE_ENABLE_AXIS0);
    delay(100);
    odriveUart.sendCommand(ODRIVE_ENABLE_AXIS1);
    delay(100);

    enabled_ = true;
    safetyTripped_ = false;
    Serial.println("[Motors] Enabled (torque/current mode)");
    return true;
}

void MotorController::disable() {
    // Zero current first
    balanceCurrent_ = 0.0f;
    yawCurrent_ = 0.0f;
    sendAxisCurrent(0, 0.0f);
    sendAxisCurrent(1, 0.0f);
    delay(50);

    odriveUart.sendCommand(ODRIVE_DISABLE_AXIS0);
    delay(50);
    odriveUart.sendCommand(ODRIVE_DISABLE_AXIS1);
    delay(50);

    enabled_ = false;
    Serial.println("[Motors] Disabled");
}

void MotorController::emergencyStop() {
    Serial.println("[Motors] EMERGENCY STOP");
    balanceCurrent_ = 0.0f;
    yawCurrent_ = 0.0f;
    sendAxisCurrent(0, 0.0f);
    sendAxisCurrent(1, 0.0f);
    disable();
}

void MotorController::setBalanceCurrent(float amps) {
    balanceCurrent_ = constrain(amps, kPIDOutputMin, kPIDOutputMax);
}

void MotorController::setLinearVelocity(float mps) {
    // In torque mode, linear velocity control requires an outer loop (future).
    // For now, this is a no-op. Navigation will add a drive PID later.
    (void)mps;
}

void MotorController::setTurnRate(float radps) {
    // Convert turn rate to differential current
    // Simple proportional: radps → amps differential
    float turn_current = radps * 0.5f;  // Tune this scale factor later
    yawCurrent_ = constrain(turn_current, -kMaxCurrentAmps, kMaxCurrentAmps);
}

void MotorController::update(float current_pitch_deg) {
    odriveUart.update();

    // Auto-recover
    if (safetyTripped_) {
        if (fabsf(current_pitch_deg) < kRecoverTiltDeg) {
            if (recoverStartMs_ == 0) {
                recoverStartMs_ = millis();
            } else if (millis() - recoverStartMs_ >= kRecoverHoldMs) {
                Serial.printf("[Motors] Auto-recover — pitch=%.1f within %.0f deg\n",
                              current_pitch_deg, kRecoverTiltDeg);
                safetyTripped_ = false;
                recoverStartMs_ = 0;
                enable();
            }
        } else {
            recoverStartMs_ = 0;
        }
        return;
    }

    if (!enabled_) return;

    // Safety cutoff
    if (fabsf(current_pitch_deg) > kMaxTiltDeg) {
        Serial.printf("[Motors] SAFETY — pitch=%.1f exceeds %.0f deg\n",
                      current_pitch_deg, kMaxTiltDeg);
        emergencyStop();
        safetyTripped_ = true;
        recoverStartMs_ = 0;
        return;
    }

    applyCurrents();
}

void MotorController::applyCurrents() {
    // Balance current same on both wheels + yaw differential
    float left = balanceCurrent_ + yawCurrent_;
    float right = balanceCurrent_ - yawCurrent_;

    // Clamp to safety limit
    left = constrain(left, -kMaxCurrentAmps, kMaxCurrentAmps);
    right = constrain(right, -kMaxCurrentAmps, kMaxCurrentAmps);

    leftCurrent_ = left;
    rightCurrent_ = right;

    sendAxisCurrent(kLeftMotorAxis, left);
    sendAxisCurrent(kRightMotorAxis, right);
}

void MotorController::sendAxisCurrent(uint8_t axis, float amps) {
    float dir = (axis == 0) ? kAxis0Direction : kAxis1Direction;
    char cmd[32];
    snprintf(cmd, sizeof(cmd), ODRIVE_CURRENT_CMD_FMT, axis, amps * dir);
    odriveUart.sendCommand(cmd);
}

bool MotorController::hasError(int& err0, int& err1) {
    err0 = (int)odriveUart.readFloat("r axis0.error\n");
    err1 = (int)odriveUart.readFloat("r axis1.error\n");
    return (err0 != 0 || err1 != 0);
}

bool MotorController::isEnabled() {
    return enabled_;
}

bool MotorController::isReady() {
    int err0, err1;
    return !hasError(err0, err1);
}

bool MotorController::isSafetyTripped() {
    return safetyTripped_;
}

float MotorController::getAxisVelocity(uint8_t axis) {
    // Now returns current (Amps), not velocity — name kept for telemetry compat
    if (axis == 0) return leftCurrent_;
    if (axis == 1) return rightCurrent_;
    return 0.0f;
}

bool MotorController::calibrateAxis(uint8_t axis, uint32_t timeout_ms) {
    char cmd[48];
    snprintf(cmd, sizeof(cmd), "w axis%d.requested_state 3\n", axis);
    odriveUart.sendCommand(cmd);

    uint32_t start = millis();
    while (millis() - start < timeout_ms) {
        delay(1000);
        char readCmd[48];
        snprintf(readCmd, sizeof(readCmd), "r axis%d.current_state\n", axis);
        float state = odriveUart.readFloat(readCmd, 1000);
        Serial.printf("[Motors] Axis %d state: %d\n", axis, (int)state);

        if ((int)state == 1) {
            snprintf(readCmd, sizeof(readCmd), "r axis%d.error\n", axis);
            float err = odriveUart.readFloat(readCmd, 1000);
            snprintf(readCmd, sizeof(readCmd), "r axis%d.motor.error\n", axis);
            float merr = odriveUart.readFloat(readCmd, 1000);
            snprintf(readCmd, sizeof(readCmd), "r axis%d.encoder.error\n", axis);
            float eerr = odriveUart.readFloat(readCmd, 1000);
            Serial.printf("[Motors] Axis %d: err=%d motor=%d enc=%d\n",
                          axis, (int)err, (int)merr, (int)eerr);
            return ((int)err == 0 && (int)merr == 0 && (int)eerr == 0);
        }
    }
    Serial.printf("[Motors] Axis %d calibration TIMEOUT\n", axis);
    return false;
}
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

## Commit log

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2025-10-12 feat: initial repository structure with I2C architecture foundation
    - Created complete monorepo directory structure per source tree specification
    - Added shared/i2c_registers.h with common I2C register protocol
    - Updated .gitignore for Python, ROS2, PlatformIO, and environment files
    - Added config/api-keys.template.env for secure API key management
    - Updated README.md with corrected documentation links
    - Restructured docs into sharded format (architecture/, prd/)
    This commit establishes the foundation for OLAF's modular architecture
    with I2C-based communication between Raspberry Pi orchestrator and
    5 ESP32 smart peripheral modules.
2025-10-12 qa: comprehensive review of Story 1.1 - PASS
    Quality Gate: PASS (100/100)
    - All 8 acceptance criteria met
    - Exemplary I2C protocol design with comprehensive documentation
    - Security best practices followed (proper secrets management)
    - README links correctly updated for sharded documentation
    - No technical debt identified
    - Zero refactoring required
    Recommendation: Ready for Done, proceed to Story 1.2
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2025-10-13 docs: clarify UART architecture for servo controllers and motor control
    Architecture clarifications for dual UART interfaces:
    - Ears+Neck ESP32 (0x09): UART1→Ear Controller (4× SCS0009), UART2→Neck Controller (3× STS3215)
    - Base ESP32 (0x0B): UART1→ODrive motor controller, UART2→Kickstand servo (1× STS3215)
    - Body ESP32 (0x0A): Optocoupler for projector power button (not relay)
    Updated documentation:
    - components.md: Added explicit UART interface assignments for all servo controllers
    - high-level-architecture.md: Updated ASCII diagram to show UART1/UART2 connections
    - Technical summary revised: 4 modules (not 5), dual UART architecture, optocoupler control
    Key corrections:
    - Kic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
2025-10-13 docs: update README to reflect 4-module architecture and 12-epic roadmap
    Major updates to align README with current architecture and PRD:
    Architecture changes:
    - 4 modules (not 5): Head (0x08), Ears+Neck (0x09), Body (0x0A), Base (0x0B)
    - Ears+Neck consolidated on shared ESP32 with dual UART controllers
    - New Body module: heart LCD, LEDs, projector control (optocoupler)
    - GC9A01 Round TFT displays (240×240, 60 FPS) replace OLED references
    - ESP32-S3-WROOM-2 modules (not ESP32-WROOM-32)
    Roadmap updates:
    - 12 epics with faster milestone cadence (vs original 4 epics)
    - Timeline: 26-36 weeks (6-9 months of weekend development)
    - Epic 01 focuses on heart LCD (not head module)
    - Added configura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
2025-10-15 fix: remove unavailable software-properties-common package from Pi setup script
    The software-properties-common package is not available on Raspberry Pi OS
    and is not needed for ROS2 installation. Removed it from the prerequisites
    to prevent installation failures.
2025-10-15 fix: map Debian codename to Ubuntu codename for ROS2 repository
    The script was using $UBUNTU_CODENAME which doesn't exist on Debian-based
    Raspberry Pi OS. Added proper mapping:
    - Debian Bookworm (12) -> Ubuntu Jammy (22.04)
    - Debian Trixie (13) -> Ubuntu Noble (24.04)
    This fixes the malformed apt sources list error.
2025-10-15 docs: clarify Raspberry Pi OS Bookworm requirement for ROS2 Humble
    Updated setup instructions to explicitly require Debian Bookworm instead
    of Trixie. ROS2 Humble packages depend on Python 3.10 libraries which are
    not available in Debian Trixie (Python 3.12).
    Changes:
    - Added warning to select "Raspberry Pi OS (Legacy, 64-bit)" with Bookworm
    - Clarified that Trixie is not supported
    - Updated script description to mention Ubuntu Jammy repositories
2025-10-15 refactor: migrate to ROS2 Jazzy with Ubuntu 24.04 and manual setup steps
    Major changes:
    - Switched from ROS2 Humble to ROS2 Jazzy (LTS until 2029)
    - Changed OS requirement from Raspberry Pi OS Bookworm to Ubuntu Server 24.04
    - Replaced automated setup script with manual step-by-step instructions
    - Updated both Pi and PC setup documentation for Jazzy
    - Removed install_ros2_humble_pi.sh and install_ros2_jazzy_pi.sh scripts
    Rationale:
    - ROS2 Jazzy has official Tier 1 support for Ubuntu 24.04 ARM64
    - Raspberry Pi OS Trixie lacks compatible ROS2 packages
    - Manual instructions provide better transparency and learning
    - Easier to troubleshoot individual steps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
2025-10-18 docs: update network test to use ros2 topic pub/echo instead of launch files
    - Replace driver node launch test with simple topic pub/echo test
    - Add note that driver nodes haven't been implemented yet
    - Provide clear step-by-step instructions for bidirectional testing
    - Fix bash escaping issue with exclamation mark in quotes
    - Test both Pi → PC and PC → Pi communication
    This allows users to verify network setup works before implementing nodes.
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2025-10-23 refactor: upgrade to ESP32-S3-WROOM-2 N16R8 and fix pin assignments
    Update all documentation and configuration to use ESP32-S3-WROOM-2
    N16R8 variant (16MB Flash, 8MB PSRAM) instead of N8R8 (8MB Flash).
    Additionally corrected pin assignments throughout to match ESP32-S3
    defaults and standardized architecture.
    Hardware Changes:
    - Flash: 8MB → 16MB (N8R8 → N16R8)
    - PSRAM: 8MB (unchanged)
    Pin Assignment Updates (ESP32-S3 defaults):
    - SPI MOSI: GPIO23 → GPIO11
    - SPI SCK: GPIO18 → GPIO12
    - SPI CS: GPIO5 → GPIO10
    - I2C SDA: GPIO21 → GPIO8 (standardized across all modules)
    - I2C SCL: GPIO22 → GPIO9 (standardized across all modules)
    - DC: GPIO2 → GPIO5
    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
2025-10-25 fix: correct ESP32-S3 SPI pin assignments in story 1.3
    - Changed GPIO18→GPIO12 (SPI SCK) and GPIO23→GPIO11 (SPI MOSI)
    - Added documentation for A0/DC pin equivalence
    - Added LED pin (GPIO10) for optional backlight control
    - ESP32-S3 uses different default SPI pins than ESP32-WROOM-32
2025-10-25 fix: update I2C pins to GPIO8/GPIO9 for ESP32-S3 in story 1.3
    - Changed I2C SDA from GPIO21 to GPIO8
    - Changed I2C SCL from GPIO22 to GPIO9
    - GPIO8/GPIO9 are commonly available on ESP32-S3 dev boards
    - Added note about flexible GPIO mapping on ESP32-S3
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2025-10-26 feat(story-1.3): dual GC9A01 displays working with TFT_eSPI
    Task 5: Test SPI Displays - Successfully initialized dual eye displays
    after debugging multiple issues.
    Key achievements:
    - Fixed ESP32-S3 crash by enabling USE_HSPI_PORT define
    - Resolved duplicate pin definitions (ESP8266 vs ESP32-S3)
    - Verified SPI communication at 20MHz
    - Both displays render test patterns correctly
    - Added comprehensive build log documenting debug journey
    Known limitation: Independent CS control deferred to future work
    Technical details:
    - Library: TFT_eSPI v2.5.43 configured for GC9A01 driver
    - Platform: espressif32 with ESP32-S3-DevKitC-1
    - Pin map: MOSI=11, SCK=12, CS=5, DC=2, RST=4, BL=10
    🤖 Generated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
    [Head Base parts - head-front-panel.stl]
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2025-10-27 feat(story-1.3): complete dual display and I2C communication testing
    Tasks 5, 6, 7: Successfully implemented and tested dual GC9A01 displays
    with I2C slave communication from Raspberry Pi.
    - Fixed ESP32-S3 I2C slave initialization (Wire.setPins + Wire.begin)
    - Configured TFT_eSPI via platformio.ini build flags (survives pio clean)
    - Added USE_HSPI_PORT define (critical fix for espressif32 >= 6.7.0)
    - Commented out TFT_CS for manual dual-display control
    - Verified I2C device detection at address 0x08
    - Tested text transmission from Pi to displays via I2C
    - I2C: SDA=GPIO8, SCL=GPIO9, Address=0x08, 400kHz
    - Displays: GC9A01 240x240, SPI 20MHz, manual CS co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
    [main.cpp]
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2025-10-27 journal(james): The Day OLAF Opened Its Eyes
    Daily journal entry for October 27, 2025 - Story 1.3 completion session.
    Chronicles the full journey from compiler errors to working dual displays:
    - Morning: Include path fixes and ESP32-S3 crashes
    - Afternoon: TFT_eSPI configuration and USE_HSPI_PORT discovery
    - Late Afternoon: Permanent build flag solution
    - Evening: Successful I2C communication tests
    - Documentation: BOM creation, README writing, story completion
    - Fixed ESP32-S3 Guru Meditation crash
    - Configured dual GC9A01 displays with manual CS control
    - Established I2C communication (device 0x08 detected)
    - Created permanent configuration via platformio.ini build flag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
2025-10-29 feat(story-1.4): redesign eye expressions with chopsticks1-inspired shapes and colors
    Redesigned eye rendering system inspired by Vector robot and chopsticks1
    face controller with distinct shapes and colors for each expression.
    - Added EyeShape enum: rounded rects, circles, arcs (up/down), lines
    - Implemented shape-based rendering with color coding:
    * NEUTRAL: Cyan rounded rectangles (steady gaze)
    * HAPPY: Green upward arcs (smiling eyes)
    * CURIOUS: Cyan circles (asymmetric sizing)
    * THINKING: Cyan rounded rects (looking up-right)
    * CONFUSED: Orange horizontal lines (squinting)
    * SAD: Blue downward arcs (frowning eyes)
    * EXCITED: White large circles (wide-eyed)
    - Impr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
    [i2c_slave.cpp, i2c_slave.h, main.cpp]
2025-10-29 fix(story-1.4): improve blink animation and expression transitions
    Three improvements for more natural eye behavior:
    1. Changed closed eye shape during blink:
    - Now draws very thin curved lines (2-3 pixels)
    - Visually distinct from CONFUSED expression (which uses thicker straight lines)
    - More natural eyelid appearance
    2. Added blink-during-transition:
    - Expression changes trigger automatic blink
    - Creates "close with old expression, open with new" effect
    - More natural transition between emotional states
    3. Reduced blink flicker with discrete frames:
    - Changed from continuous interpolation to 4 discrete frames
    - Frame sequence: OPEN -> HALF_CLOSED -> FULLY_CLOSED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
2025-10-29 fix(story-1.4): eliminate transition flicker by snapping expression during blink
    Changed transition behavior to snap to new expression when eyes are closed
    instead of continuously redrawing during interpolation.
    Before:
    - Continuous redrawing during transition (causes flicker)
    - Gradual interpolation visible on screen
    After:
    - Expression snaps to new state at blink midpoint (eyes closed)
    - Effect: Close with old → Switch while closed → Open with new
    - No visible flicker, clean transitions
    Technical: Snap occurs at blink_progress 0.4-0.6 (fully closed frame)
2025-10-29 feat(story-1.5): implement ROS2 head driver node with I2C bridge
    Implemented complete ROS2 head driver node that translates ROS2 topics
    to I2C register writes for Head module (address 0x08).
    Features:
    - I2C communication layer with 3-attempt retry logic (100ms delay)
    - Module health check on startup (verifies module ID)
    - Subscribes to /olaf/head/expression and /olaf/head/blink
    - Publishes /olaf/head/status at 10Hz
    - Comprehensive error handling with graceful degradation
    - Extensive inline comments and docstrings per coding standards
    Tasks completed: 1-6, 8 (partial)
    Task 7 (testing) remains incomplete - requires hardware and ROS2 build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
2025-10-30 chore: clean up stray build artifacts and improve gitignore
    - Remove stray build/ folder at root (leftover from migration testing)
    - Clean and rebuild ROS2 workspace to remove old package artifacts
    (olaf_orchestrator, olaf_interfaces -> orchestrator, interfaces)
    - Improve .gitignore: /build/ now only ignores root-level build folder
    - ROS2 builds correctly isolated in ros2/build/
    Verification:
    - ✅ No build artifacts at root
    - ✅ ROS2 builds successfully with new package names
    - ✅ Clean workspace (only interfaces and orchestrator in build/)
    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
2025-11-01 feat(ros2): add minimal coordinator for end-to-end expression pipeline validation
    Implement minimal_coordinator node to validate the complete orchestrator→ROS2→I2C→ESP32→SPI pipeline for Story 1.6. This provides a simple autonomous test harness that cycles through all 7 expressions, proving the integration works before building the full personality system.
    Key changes:
    - Created minimal_coordinator node with 10-second expression cycling
    - Updated Story 1.6 v1.2 to remove blink topic (firmware handles autonomously)
    - Marked Story 1.5 as Ready for Review after successful hardware testing
    - Fixed firmware blink timing to cap at 8 seconds max interval
    - Added ros2_nodes package structur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
2025-11-08 docs: add Epic 3 Complete Head Assembly documentation and stories
    - Epic 3 document: Complete head assembly with eyes, ears, and neck
    - All 11 stories (3.1-3.11) with detailed acceptance criteria and tasks
    - Hardware: 3D printing, PCB assembly, servo integration, neck gimbal
    - Firmware: Head module (presence sensor), Ears+Neck module (7 servos)
    - Software: ROS2 drivers, coordinated expression system
    - Testing: 30-minute stability test, integration validation
    - Documentation: Assembly guides, BOM, wiring diagrams, build-in-public content
    - Hardware: Neck v2 3D model parts (base plate, connector, servo horn)
    - Dual ESP32 modules: Head (0x08), Ears+Neck (0x09)
    - PCB so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
    [neck v2 -parts - neck base connecter.stl]
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2025-12-06 feat: add Epic 5 (torso) and Epic 6 (base) planning and expand project structure
    Add comprehensive documentation for two new epics: torso power/display system and self-balancing base. Update project configuration and fix display orientation issues.
    **Epic 5 - Torso (Power & Heart Display):**
    - PRD and 9 user stories covering 3D printing, LCD assembly, power system, ESP32 firmware, ROS2 integration
    - Power system with buck converter, heart-shaped LCD for status display
    - Raspberry Pi integration in torso module
    **Epic 6 - Self-Balancing Base:**
    - 10 user stories for mobile platform with ODrive motor control
    - IMU (MPU6050) integration, PID balancing, SLAM navigation
    - Base ESP32 firmware an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
    [ear base - bottom bracket.stl, head-top - bottom bracket.stl, level_support.stl]
2025-12-16 refactor: major project reset and documentation overhaul
    Archive old documentation and code, create fresh concise documentation structure based on 20 weeks of learning and clarity gained from build experience.
    **What Changed:**
    - Archive entire old structure (docs/, firmware/, hardware/, ros2/, etc.) to archive/ folder
    - Create new documentation/ folder with streamlined content
    - Add archive/ to .gitignore
    - Complete README.md rewrite with 3D concept image, build journey, and clear project positioning
    **New Documentation:**
    - documentation/brief.md: Condensed project brief with problem statement, architecture, MVP scope
    - documentation/media/: Project media assets (3D CAD concept)
    - README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
    [ear base - bottom bracket.stl, epic1_bom.csv, eye cover.stl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]
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2026-01-31 refactor: pivot to Fusion HAT architecture (4 ESP32 → 2 ESP32)
    Major architecture changes to reduce soldering complexity:
    - Replace 4 ESP32 modules with 2 ESP32 + Pi direct control
    - Add Sunfounder Fusion HAT+ for PWM, WS2812, I2S
    - Update to Ubuntu 24.04 + ROS2 Jazzy
    Module changes:
    - HEAD: New ESP32 module for OLED eyes (I2C 0x10)
    - BASE: Keep ESP32 for self-balancing (I2C 0x11)
    - NECK: Now Pi-controlled via USB Waveshare adapter
    - EARS: New Pi-controlled module via USB Waveshare adapter
    - INDICATOR: New Pi-controlled WS2812 module (24 LEDs)
    - TORSO: Removed (4" Pi display replaces heart display)
    Archived old modules:
    - head-ears/ → archive/modules/head-ears/
    - torso/ → archive/mo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
    [HEad module_v2.fzz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]
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2026-02-07 fix: unlock/lock EEPROM when writing servo ID and offset
    - Add _unlock_eeprom() and _lock_eeprom() methods
    - Unlock before writing, lock after to persist changes
    - Register 55 (LOCK): 0=unlocked, 1=locked
    [ears_servo_driver.py]
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2026-02-07 fix: use raw position 512 for centering, add go_to_position()
    - center_all() now writes position 512 directly
    - go_to_position() for raw position control
    - Test uses raw positions (512=center, 562=small move)
    [ears_servo_driver.py]
2026-02-07 fix: use current position as zero, reduce test to 5 counts
    - Read current position as zero reference for each servo
    - Test movement reduced from 50 to 5 counts
    [ears_servo_driver.py]
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2026-02-07 fix: correct center position to 511, try both lock registers
    - Center position is 511 (not 512) per Waveshare docs
    - Try lock register 55 and 48 (for older servos)
    - Reduce test movement to 2 counts
    Sources: Waveshare Wiki, Hanson Robotics servo_experiments
    [ears_servo_driver.py]
2026-02-07 fix: use correct SCS protocol settings from Servo-diagnostic
    - PacketHandler(1) for SCS protocol (was 0)
    - Lock register at address 48 (was 55)
    - Add ADDR_ID constant at address 5
    Source: Adam-Software/Servo-diagnostic
    [ears_servo_driver.py]
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2026-02-10 fix: use software center_position in config instead of EEPROM offset
    SCS0009 EEPROM offset register doesn't work as expected. Store raw
    center positions in config/servo-ids.yaml instead. set-center command
    reads live positions and saves to config file.
    [servo-ids.yaml]
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2026-02-10 fix: correct right pan servo direction
    [servo-ids.yaml]
2026-02-10 fix: correct left pan servo direction to outward
    [servo-ids.yaml]
2026-02-10 fix: increase ear servo base speed to 300
    [servo-ids.yaml]
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2026-02-10 fix: resolve config path for both source tree and colcon install
    [ears_calibration.py, ears_servo_driver.py]
2026-02-10 fix: flip left_tilt direction to -1 (mirror of right tilt)
    [servo-ids.yaml]
2026-02-10 feat: Doberman-style ear presets with corrected hardware limits
    Limits now match actual servo range per center position.
    Presets based on Doberman ear body language research.
    [servo-ids.yaml]
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2026-02-13 feat: complete story 1.3 — head ESP32 firmware with I2C testing
    All tasks complete: dual GC9A01 eye displays, sprite-based animation,
    I2C slave at 0x08, WS2812 LED strip, OTA updates, demo mode.
    Fixed angry expression mirroring between eyes. Validated all I2C
    commands from Pi (expressions, blink, look, system status, LEDs).
    Added OTA docs to README and full I2C register map to wiring.md.
    [animation_engine.cpp, config.h, display_driver.cpp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]
2026-02-13 feat: add head ROS2 driver node with I2C client (story 1.4)
    HeadNode subscribes to /olaf/head/{expression,blink,look,status}
    and translates to I2C register writes to ESP32 at 0x08.
    HeadI2CClient wraps smbus2 with expression/status string mapping,
    signed byte look direction, and error handling. 23 unit tests pass.
    [head_i2c_client.py, head_node.py]
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2026-02-14 fix: add overload auto-recovery to all servo write paths
    Extracted _write_pos helper with overload detection and torque toggle.
    move_pose was calling WritePosEx directly for linkage servos, bypassing
    overload clearing. Now all servo writes go through _write_pos.
    [neck_servo_driver.py]
2026-02-14 fix: clear latched overload on driver init
    STS3215 silently ignores WritePosEx when overload is latched (error byte
    returns 0). Toggle torque for all servos during init to clear any stale
    overload from previous sessions.
    [neck_servo_driver.py]
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2026-03-17 feat: expressive ears, WALL-E neck, layered color eye firmware
    - expressions.py: 10 ear presets (added angry/surprised/sleepy),
    redesigned angles from dog ear reference, cap right_pan ≤55° to
    avoid servo limit binding
    - olaf_demo.py: WALL-E-style neck speeds (snaps 3000, sad 200),
    compound pan+tilt+roll, happy nod, excited 4-pass bounce sequence
    - animation_engine: full layered eye rendering — teal iris circle +
    expression eyelid mask + dark pupil + specular highlight dot;
    replaces flat white shapes with colored cartoon eye style
    [animation_engine.cpp]
2026-03-17 fix: happy eyes now ^ ^ style, double highlights on all expressions
    - Happy eyelid masks bottom half (not top) for proper smiling ^ ^ shape
    - Pupil visible on happy expression
    - Double anime-style highlights (large + small) on all expressions
    - Happy highlights positioned in visible top arc area
    [animation_engine.cpp]
2026-03-17 feat: LEDs only active during speaking, fix demo status flow
    LED firmware: only SPEAKING state runs animation, all other states
    turn LEDs off (clearAll). Demo: add status("woke_up") after Happy
    scene so LEDs don't stay lit through remaining emotion scenes.
    [led_strip.cpp]
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2026-05-20 checkpoint: Story 7.2 vocalization layered-action (review) + Epic 7 in-flight bundle
    Story 7.2 (vocalization layered_action) — hardware-confirmed across all 6
    tags on real OLAF after 4 review iterations. Map-driven, randomized
    transient on neck + ears + optional eye that lands on top of speech_emotion
    / mood / activity (AR12 additive). Eye override is optional per tag; nod /
    shake / clears_throat stay on the composed speech_emotion eye while
    laughter / sigh / gasp flash their own. `_VocalizationAction` in
    render_loop replaces the old hard-coded `_Gesture.SHAPES`. New
    vocalization_stepper.py mirrors eye_stepper pattern for hardware review.
    Also bundles the Epic 7 in-flight work that hadn't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
    [bmad-help.csv, files-manifest.csv, module-help.csv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]
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2026-05-22 feat(7.3): drowsy sleepy blink + deeper sleep pose (neck 28°, ears less splay)
    - Head fw: EXPR_SLEEPY blinks slowly on a random 4–9s cadence even while
    asleep; closedness cap now applies to the WAKE part only so the blink
    still closes fully (dips from half-lid to shut and back).
    - Neck tilt clamp raised ±20→±28 (neck_adapter + servo-ids.yaml linkage
    min/max) — Kamal-confirmed the linkage reaches 28° without binding.
    - sleeping pose: neck tilt -18→-28 (deeper droop), ear pan 35→25 (less
    outward splay) so the whole body reads asleep, not just the eye.
    - test_review_hardening neck-clamp asserts against _LIMITS (now ±28).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
    [servo-ids.yaml]
2026-05-22 fix(7.3): content distinct from excited, ears clamp warning de-spammed, gentler working turn
    - content eye: calmer "pleased" — smaller squat cropped circle, moderate
    pupil (clearly < excited's 0.48), warm tint, no sparkle (was reading
    too like excited). Firmware OTA-flashed.
    - ears driver: clamp warning logs ONCE per out-of-range episode per
    servo instead of every ~200Hz tick (was flooding stdout).
    - activity poses: right_tilt authored within the servo's physical -7
    (sleeping/going_to_sleep were -25/-12 → clamped every tick); left ear
    keeps its deeper droop. No visual change, just no clamp.
    - working.thinking/delegating neck pan ±15 → ±8 (less head rotation).
    Co-Authored-B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
    [animation_engine.cpp, ears_servo_driver.py]
2026-05-22 fix(head-fw): PROCESSING LED = whole-strip pulse-blink, distinct from LISTENING
    Listening (traveling wave) and processing (bouncing comet) read alike —
    both a moving bright region in the same mood tint. Processing is now a
    synchronized whole-strip pulse-blink (sharp beat + dim background floor)
    so "working" is clearly different from "listening". OTA-flashed.
    [led_strip.cpp]
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
